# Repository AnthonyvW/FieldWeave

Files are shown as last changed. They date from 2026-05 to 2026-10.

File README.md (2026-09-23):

# FieldWeave - Low Cost Gigapixel Imaging Machine








FieldWeave is an open-source, gigapixel imaging system built on a modified off-the-shelf 3D printer. It automates sample capture, focus stacking, and DPI calibration, producing high resolution images across a wide range of fields. See it in action on the [FieldWeave website](https://www.fieldweave.com), which includes an interactive gallery for browsing full-resolution scans.

**If FieldWeave is useful to you, please consider giving it a star and supporting its development. See [Support FieldWeave](#support-fieldweave) below.**

## Features

* **Automated Scanning**: Utilizes 3D printer mechanics for precise, repeatable sample movement.
* **High-Resolution Imaging**: Captures gigapixel images across dendrochronology, geology, life sciences, museum, manufacturing, and forensic use cases.
* **Focus Stacking**: Built-in stacking via FocusWeave.
* **Automated DPI Calibration**: Calibrates scan resolution automatically against a compatible micrometer slide.
* **Modular Design**: Easily adaptable to different sample types, lenses, and imaging requirements.

## Examples

### [Browse the full gallery at fieldweave.com/gallery](https://www.fieldweave.com/gallery)

<table>
  <tr>
    <td width="33%">
      <a href="https://www.fieldweave.com/gallery/image/cross-section-1">
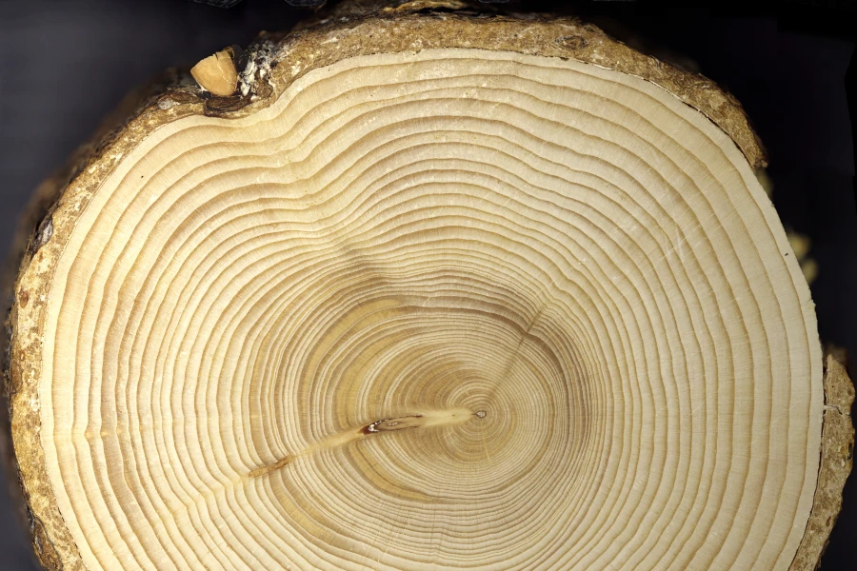
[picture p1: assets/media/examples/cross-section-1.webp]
Cross section of a black spruce tree core, click to view full resolution on the FieldWeave gallery
        
      </a>
    </td>
    <td width="33%">
      <a href="https://www.fieldweave.com/gallery/image/western-hemlock-core">
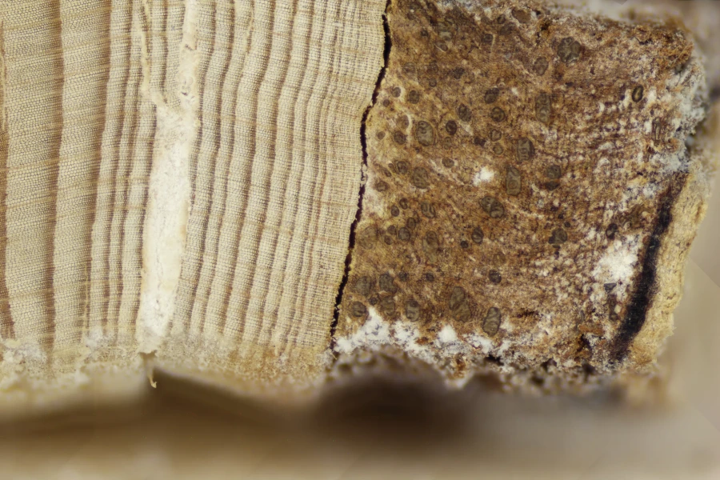
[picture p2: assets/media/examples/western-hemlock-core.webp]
Western hemlock tree core, click to view full resolution on the FieldWeave gallery
        
      </a>
    </td>
    <td width="33%">
      <a href="https://www.fieldweave.com/gallery/image/basswood-stem-cs">
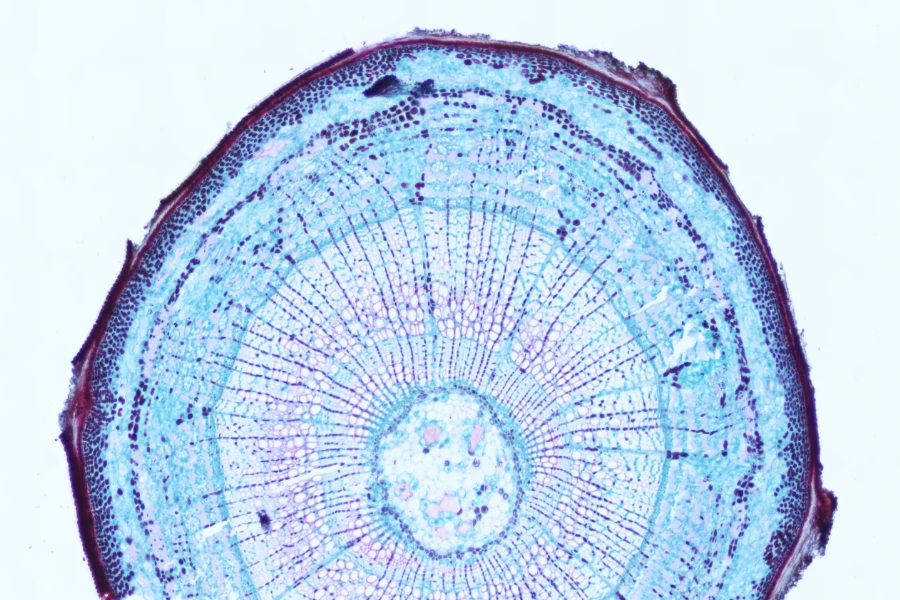
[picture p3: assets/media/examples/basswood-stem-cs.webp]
Cross section of a basswood stem, click to view full resolution on the FieldWeave gallery
        
      </a>
    </td>
  </tr>
	<tr>
    <th>Black spruce tree core cross section</th>
    <th>Western hemlock tree core</th>
    <th>Basswood stem cross section</th>
	</tr>
  <tr>
    <td width="33%">
      <a href="https://www.fieldweave.com/gallery/image/rusty-7-16-drill-bit">
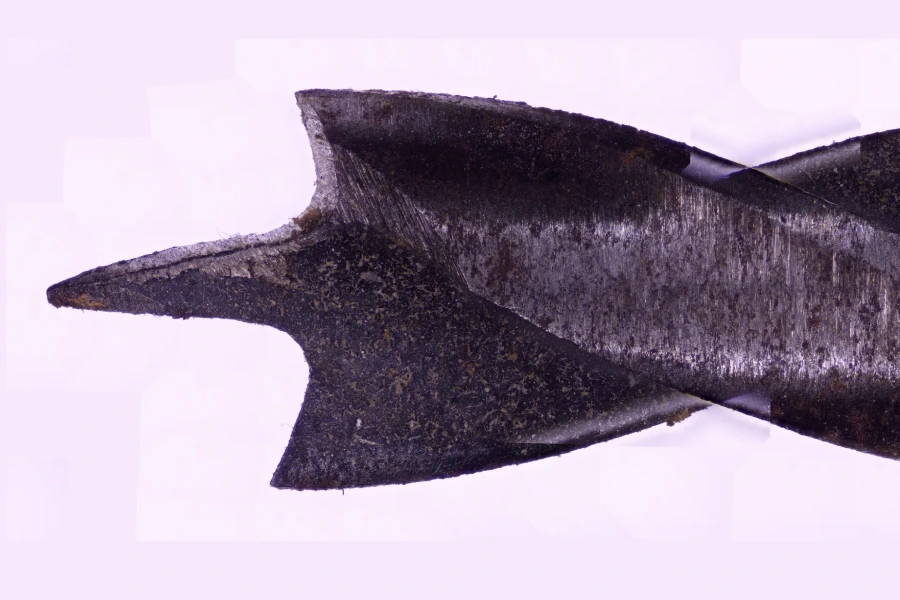
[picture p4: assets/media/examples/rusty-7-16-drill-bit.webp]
A rusty 7/16 drill bit, click to view full resolution on the FieldWeave gallery
        
      </a>
    </td>
    <td width="33%">
      <a href="https://www.fieldweave.com/gallery/image/us-dime-back">
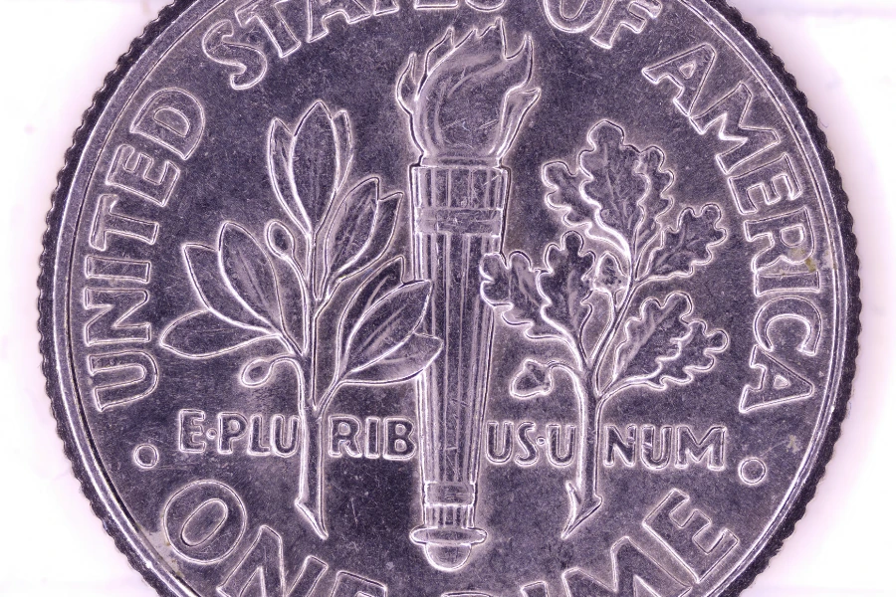
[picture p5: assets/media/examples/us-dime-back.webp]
Back of a US dime, click to view full resolution on the FieldWeave gallery
        
      </a>
    </td>
    <td width="33%">
      <a href="https://www.fieldweave.com/gallery/image/9mm-1">
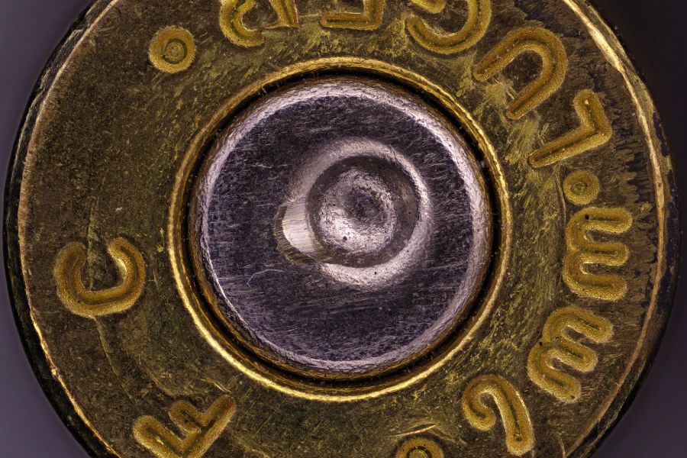
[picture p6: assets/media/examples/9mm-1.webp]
Spent 9mm bullet casing, click to view full resolution on the FieldWeave gallery
        
      </a>
    </td>
  </tr>
	<tr>
    <th>A rusty 7/16 drill bit</th>
    <th>Back of a US dime</th>
    <th>Spent 9mm bullet casing</th>
	</tr>
</table>

## Support FieldWeave

FieldWeave is free and GPL-licensed, and stays that way through community support. If it's useful to your lab, workflow, or project, consider chipping in. Funding goes directly toward hardware, testing, and development time.

* **GitHub Sponsors**: [github.com/sponsors/AnthonyvW](https://github.com/sponsors/AnthonyvW)
* **Ko-fi**: [ko-fi.com/procerand](https://ko-fi.com/procerand)

Have a specific feature your lab needs? [Commission a feature](https://www.fieldweave.com/contact) it gets built for you and becomes available to everyone.

## Getting Started

### Prerequisites

* **Hardware**: A [compatible 3D printer](#3d-printer-compatibility) modified for imaging purposes, a light, and a [compatible camera](#confirmed-compatible-cameras). The 3D printer may also require an additional cable to connect your PC to the printer. Note that this modification will likely void the warranty if you disconnect any cables, so test the 3D printer to ensure the motion system works before doing this.
  * For the light I recommend using the [Amscope 144 led ring light](https://www.amazon.com/dp/B00JZJO7YC). If you use this, make sure to 3D print the light pads to prevent scratching the lens.
  * If using an Amscope camera, I highly recommend using this ([100x Microscope Lens for Raspberry Pi](https://www.amazon.com/100X-Microscope-Lens-Magnification-Compatible/dp/B0C1CC79TX)) industrial lens as it provides minimal distortion around the edges.
    * If going for a higher end camera such as an Amscope MU2003, we recommend the Laowa 100mm f/2.8 2x Ultra Macro APO with an EF to C adapter. However, this will require a custom mount and a better motion system than what comes on a stock Ender 3 3D printer in order to withstand the increased weight.
  * Not required, but is recommended is a thumbscrew for holding the camera in place. I use thumbscrews from [this 16 piece set](https://www.amazon.com/dp/B0DQPM68KJ) from Amazon.
  * For the automated DPI calibration to work, a compatible micrometer calibration slide is required. It is confirmed to work with the [Amscope MR400 Stage Micrometer Calibration Slide with 4-Scales](https://amscope.com/products/mr400). I am interested in adding support for additional scales.
  * If you do not have access to a 3D printer capable of printing in at least 2 colors and wish to image tree core samples, then a roll of red electrical tape to denote the center of slots.
* **High Magnification Imaging Hardware**
  * Note: This is a more expensive version that achieves far greater magnification than most other setups, however it requires additional modifications. Instead of using the 100x lens listed above, use the following parts instead for the optics.
  * To successfully do this version with 10x objective it will require upgrading the leadscrews to [350mm Tr8X2 2mm lead](https://www.amazon.com/dp/B095M8SQQV?th=1) with the appropriate [anti backlash nuts](https://www.amazon.com/dp/B085GGMCVG?th=1)
  * For the tube lense I recommend using the [Raynox DCR 250 Lens](https://www.amazon.com/Raynox-DCR-250-Super-Macro-Snap/dp/B000A1SZ2Y/) as there are 3D models present that use that.
  * [M49 to RMS Adapter](https://www.amazon.com/dp/B0FHN8FQ7T) for connecting the microscope objective to the tube lens
  * [C Mount to M42 Adapter](https://www.amazon.com/dp/B0812QPHWN) for connecting the camera to the high magnification setup.
  * For the high magnification setup, 1/4" thumbscrews are required to hold the camera in place. I use thumbscrews from [this 16 piece set](https://www.amazon.com/dp/B0DQPM68KJ) from Amazon.
  * For the microscope objective I recommend either the [Amscope 4x Metallurgic objective](https://amscope.com/products/pl4x-inf-v300) or the [Amscope 10x metallurgic objective](https://amscope.com/products/pl10x-inf-v300) both objectives are infinity plan achromatic objectives. Using anything above 10x is not recommended due to the depth of field becoming shallower than what the machine is capable of moving.
  * Due to the depth of the holes on the 3D printed parts I recommend getting a set of longer than usual metric hex keys so you can screw everything in properly. I use [this set.](https://www.amazon.com/dp/B0000CBJDV) 
* **Software**: Python 3.x and Git
* **Operating System**: Linux, Windows 10, or Windows 11

## Printer Modification

Before using FieldWeave, your 3D printer must be modified to mount the camera system in place of the print head.

### Required Printed Parts

Before modifying your printer, you must 3D print the following components:

- **Camera Mount** - Ender 3 Camera Mount.3mf – Attaches to the existing print head carriage  
- **High Magnification Camera Mount Files** - high_magnification folder
  * These are only for if you are going with the high magnification version of FieldWeave.
  * MicroscopeObjectiveMount.3mf - Attaches to print head carriage
  * Light Baffles.3mf - Insert to objective mount after screwing the mount in.
  * Amscope Mount.3mf - Attaches to the print head carriage to hold camera in place
  * RaynoxRingLightBuffer.3mf - Use if using the amscope ring light with it. You will need 3 of these. These help hold the ring light still.
- **Z-Axis Spacer** - ZAxisSpacer.3mf – Raises the Z-axis endstop to accommodate the new camera height  
    - If you are proficient with working with electronics, I suggest replacing the Z axis end stop wires with longer ones instead and mounting the Z axis limit switch higher.

> files for these parts will be provided in the `hardware/` folder of this repository.

### Optional Printed Parts
- **Calibration Slide Tray** - If using a micrometer calibration slide, this tray holds it stationary on the bed of the machine while providing a solid colored background.
- **Sample Clips** – Secure tree core samples to the print bed without manual alignment
    - SampleHolderEnd.3mf
    - SampleHolderFooter.3mf - If printing the multicolor version ensure that all the tick marks are printed in a red filament.
    - SampleHolderMiddle.3mf - You will need 3 of these. I suggest printing one of these off and ensuring that it properly fits before printing off the rest of the parts.
---

### Modification Instructions

> ! IMPORTANT ! Ensure that you have all 3D printed parts before modifying your 3D printer.

1. **Unplug 3D Printer**  
   Ensure the 3D printer is disconnected from power before working on it.

2. **Remove the Print Head**  
   Unscrew and detach the printer's hotend from the X-axis print carriage.

3. **Disconnect Wiring**  
   Carefully disconnect the hotend and heatbed wiring from the printer's control board. This prevents accidental heating or movement of the removed components.

4. **Install Camera Mount**  
   Use the print head screws to attach the printed camera mount to the same location on the print carriage where the print head was originally mounted.

5. **Insert Z-Axis Spacer**  
   Add the printed Z-axis spacer on the Z endstop, so the camera does not crash while homing.

6. **Insert sample clips**
   If you choose to use sample clips then this is the stage where you would want to slide them onto the print bed. If you printed the footer in single color you will also want to mark the center of the slots (above the slot not in the slot) with a red mark. I recommend using red electrical tape as it doesn't fade.

7. **Install Camera and Lens**  
   - Insert your digital microscope or Amscope camera into the printed mount.  
   - Screw on the imaging lens securely.  
   
8. **Install Light**  
   Install the light you will be using with FieldWeave. 
   > If using the Amscope ring light, place the light pads onto the metal tips of the screws that hold the light in place before putting the light on the lens.

9. **Plug Everything in**  
   - Plug the 3D printer back into the wall
   - Plug the 3D printer into your computer via USB for motion control.  
   - Plug in the camera using its USB interface for image capture.
   - Plug in the Light

10. **Done**

### Installation

Prerequisites\. Ensure you have the latest version of python installed, and you have git installed.

> Python : https://www.python.org/downloads/  
> Git : https://git-scm.com/downloads

1\. Clone the repository:

   ```bash
   git clone https://github.com/AnthonyvW/FieldWeave.git
   cd FieldWeave
   ```

2\. Install the required Python packages:

  ```bash
  pip install -r requirements.txt
  ```

3\.1\. Download the Amscope SDK for your camera at https://amscope.com/pages/software-downloads if you are on mac or linux, download the windows version as it includes the files for those operating systems there.

3\.2\. Move the downloaded zipped folder into 3rd_party_imports

4\. Run the install scripts:

  Windows
  ```bash
  windows_install.bat
  ```
  Linux
  ```bash
  ./ubuntu_install.sh
  ```
5\. Start FieldWeave

  Windows
  ```bash
  windows_start.bat
  ```
  Linux
  ```bash
  ./ubuntu_start.sh
  ```

---
## Confirmed Compatible Cameras
FieldWeave supports USB cameras through a modular driver architecture.

| Camera Model | Notes |
|---|---|
| Amscope MU500 | Fully tested and supported  |
| Amscope MU1000 | Fully tested, the automatic DPI calibration does not work at this camera's max resolution |
| Amscope MU1000 HS | Fully tested, the automatic DPI calibration does not work at this camera's max resolution |
| Amscope MU2003 | Fully tested, the automatic DPI calibration does not work. In addition, it needs a custom mount and higher quality lenses compared to the cameras above. I recommend the Laowa 100mm f/2.8 2x Ultra Macro APO lens with an EF to C adapter. |
| Generic USB Camera | This was tested with 2 different USB cameras and is supported  |
| Other Amscope Cameras | They should work, but are not tested. Camera mount might need to be modfied for them to fit. |

⚠️ Amscope's SDK on their website is currently out of date as of 8/15/2026. If you contact Amscope support an up to date version can be provided. The SDK version I use is Version: 59.30149.20251130

### Adding Support for New Cameras

Users are encouraged to contribute new camera interfaces by implementing the FieldWeave camera interface and submitting them as pull requests.

If your camera is not currently supported or you would like to contribute an interfaces, please open an issue or submit a pull request.

Due to the complexity of hardware integration, especially with cameras requiring proprietary APIs or SDKs full support often requires physical access to the device for development and testing. If you would like me to implement support for your camera, please be prepared to ship the device or provide access to equivalent hardware.

Alternatively, contributions of driver implementations with thorough documentation and test instructions are highly appreciated.

## 3D Printer Compatibility

FieldWeave is designed to run on 3D printers using **Marlin firmware**, which supports standard G-code over USB serial. Compatibility with other firmware types varies and may require additional configuration or is not currently supported.

> Not sure if your 3D printer will work? Plug your printer into your computer via USB, and then start FieldWeave. If the printer homes then it is compatible with FieldWeave.

## Confirmed Compatible Printers

| Printer Model | Firmware | Build Volume (mm) | Notes |
|---|---|---|---|
| Ender 3 v1 | Marlin | 220 × 220 × 250 | Fully tested and supported. It is highly recommended that you use the official linear rail upgrade kit provided by Creality for the increased camera stability. |
| Creality CR-10S Pro v2  | Marlin | 300 × 300 × 400 | Fully tested; camera mount file not available. |
| Anycubic Kobra Max v1 | Marlin | 400 × 400 × 450 | Fully tested; camera mount file not available. |
---

> Want to help verify compatibility with other printers, firmware, or cameras?  
> [Open an issue](https://github.com/AnthonyvW/FieldWeave/issues) with your setup details and test results!

## Confirmed Incompatible Printers

| Printer Model | Build Volume (mm) | Notes |
|---|---|---|
| Bambulab A1 | 220 × 220 × 250 | Properietary Firmware, cannot send gcode directly to it  |

---

## Contributing

Contributions are welcome! Please fork the repository and submit a pull request with your enhancements. For major changes, open an issue first to discuss your proposed modifications.

Not able to contribute code? Financial support is just as valuable; see [Support FieldWeave](#support-fieldweave) above ([GitHub Sponsors](https://github.com/sponsors/AnthonyvW) / [Ko-fi](https://ko-fi.com/procerand)).

## Troubleshooting

**Camera freezes when taking pictures**
- Sometimes the serial drivers conflict with the camera drivers, to fix this, plug in the camera and the 3D printer into two different sides of the computer. This forces them to be on different usb controllers which fixes any conflicts they might have.

**My Camera isn't found**
- Make sure that you have the camera drivers installed. If your camera was previously found, but is no longer found, try unplugging it and plugging it back in and ensuring the OS detects that it is plugged in as it might be a bad cable.

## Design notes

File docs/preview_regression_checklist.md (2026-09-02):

# Camera Preview Regression Checklist

Manual verification checklist for the camera preview / measurement refactor
(see the interaction-mode, input-tool-dispatch, and measurement-kind-registry
work tracked against this branch). Run through this after any change to
`UI/widgets/camera_preview.py`, `UI/widgets/preview_overlay/`, or the tabs
that drive preview interaction mode, before considering that change done.

## Navigate tab
- [ ] Click on the live feed moves the stage (once machine vision is
      calibrated and motion is ready).
- [ ] Click does nothing while uncalibrated, or while an automation routine
      is running.
- [ ] Plain mouse wheel scroll moves the Z axis; Ctrl+scroll zooms instead.
- [ ] `+`/`=`/`-` zoom in/out; arrow keys pan while zoomed, and fall through
      to normal focus navigation while not zoomed.

## Measurement tab
- [ ] Click-to-move is fully suppressed (live feed and loaded image alike).
- [ ] Plain scroll zooms (same as Ctrl+scroll); there is no Z-move path.
- [ ] Selecting a measurement kind in the sidebar, then clicking once,
      starts a draft; a dashed preview line/shape follows the cursor
      between clicks with no button held.
- [ ] Completing the required number of clicks finalizes the measurement
      and it renders with its tag/label.
- [ ] Placing a measurement while zoomed in resolves to the correct
      underlying frame position (not the zoomed/panned widget position).
- [ ] Click-and-drag while a kind is selected pans the zoomed view instead
      of placing a measurement (drag threshold ~4px).
- [ ] Clicking directly on an existing measurement's endpoint (not
      currently placing a new one) starts an endpoint drag; dragging moves
      just that point, respecting kind-specific constraints (e.g.
      Horizontal Line keeps its row fixed).
- [ ] Right-click while a multi-point placement is in progress cancels the
      draft (Arbitrary Line instead finalizes if >=2 points already placed).
- [ ] Hovering a measurement's tag shows/highlights it without a prior
      click; a delete glyph appears and removing it deletes the
      measurement.
- [ ] Pressing Delete/Backspace while hovering a tag deletes that
      measurement, with no click required first.
- [ ] Clicking a tag (not the delete glyph) opens the customize menu;
      editing there live-previews on the placed measurement; Apply commits,
      Cancel reverts.
- [ ] Switching unit (e.g. mm to px) updates all displayed labels.
- [ ] Manual DPI calibration: starting it, clicking a two-point line,
      entering a real-world length, submitting, and cancelling all behave
      as today.
- [ ] Switching to "loaded image" mode shows the static image, measurements
      persist per-image, and switching images with existing measurements
      prompts a discard confirmation.
- [ ] Leaving the tab (switching to Navigate/Calibration/Project) restores
      click-to-move and Z-scroll on return to Navigate; measurement overlay
      is hidden while another tab is showing the shared preview.

## Calibration wizards
- [ ] Camera Space Calibration: crosshair shows on the appropriate step,
      restores to its prior state when leaving the wizard, and the final
      "verify" step's click-to-move still works (default preview behavior,
      no wizard-specific code).
- [ ] DPI Calibration: crosshair on step 1, inspect-calibration overlay on
      steps 2/3, both off afterward; tick-length slider updates the overlay
      live; overlay state (crosshair/inspect-calibration) restores to
      whatever it was before entering the wizard when finishing or
      resetting.
- [ ] Slot Calibration: red-mark overlay shows only on its designated
      steps and restores to its prior state afterward.
- [ ] Re-entering a wizard after finishing it once (via the launch list)
      resets its step to 1 and re-applies step-1 overlay state.

## Cross-cutting
- [ ] Switching tabs while zoomed in a measurement/loaded-image context
      does not leave zoom/pan state corrupted when returning.
- [ ] No overlay state "leaks" between tabs (e.g. crosshair left on after
      leaving a calibration wizard when it wasn't on beforehand).

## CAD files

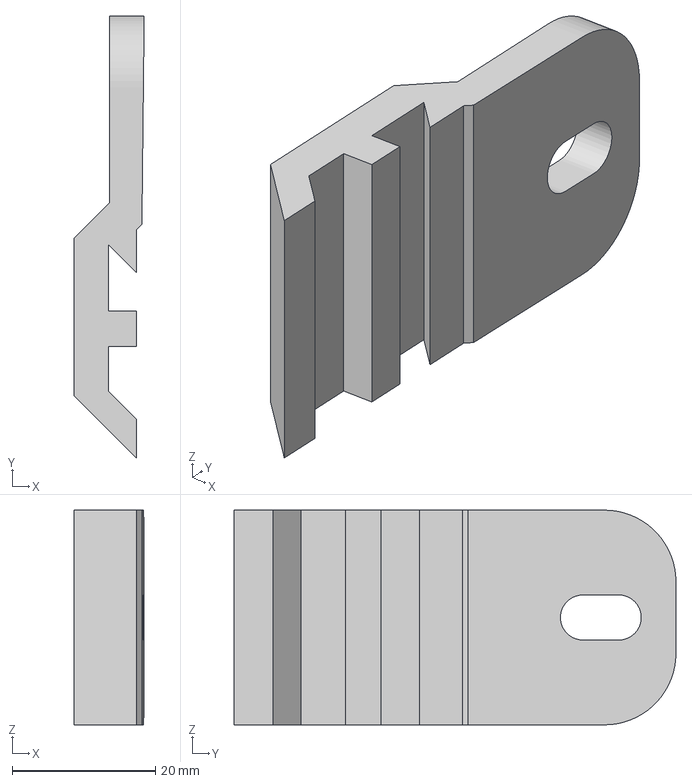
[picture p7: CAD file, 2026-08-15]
hardware/high_magnification/Amscope Mount.3mf
9.84 x 61.7 x 30.0 mm

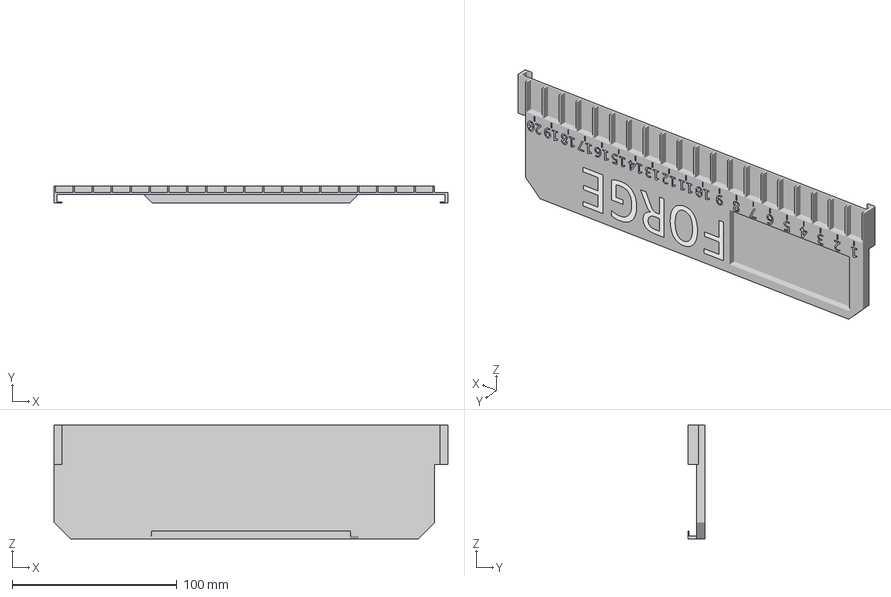
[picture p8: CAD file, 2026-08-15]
hardware/SampleHolderFooterMultiColor.3mf
239.0 x 10.3 x 69.0 mm
SampleHolderFooter

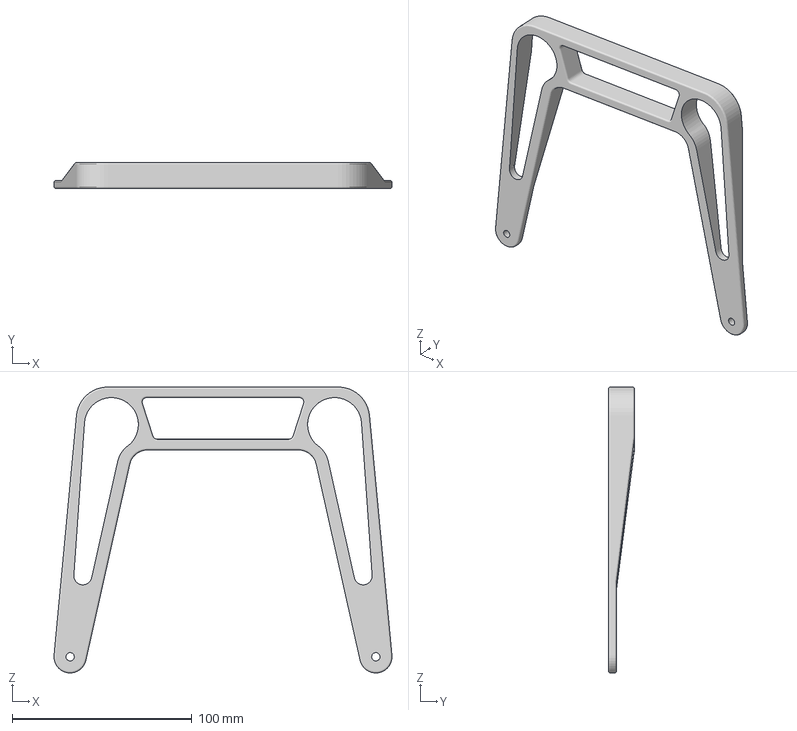
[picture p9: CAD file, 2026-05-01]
hardware/handle.3mf
187.9 x 14.5 x 159.0 mm

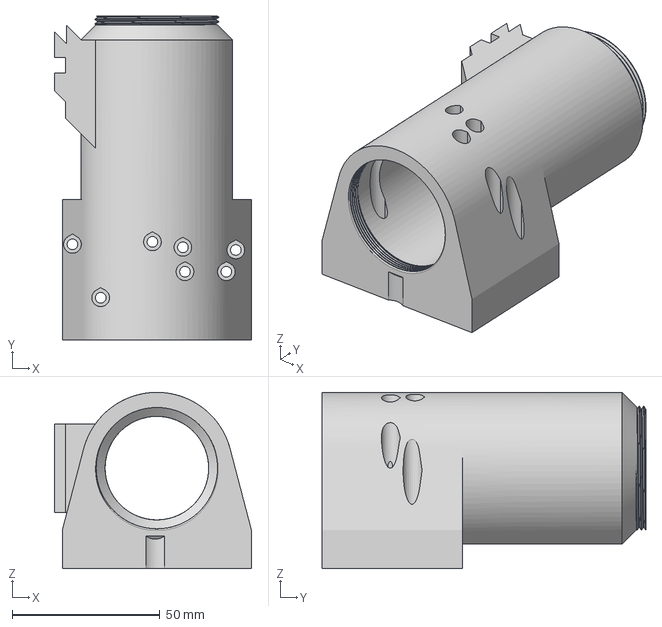
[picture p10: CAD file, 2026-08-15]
hardware/high_magnification/MicroscopeObjectiveMount.3mf
66.6 x 109.5 x 59.6 mm

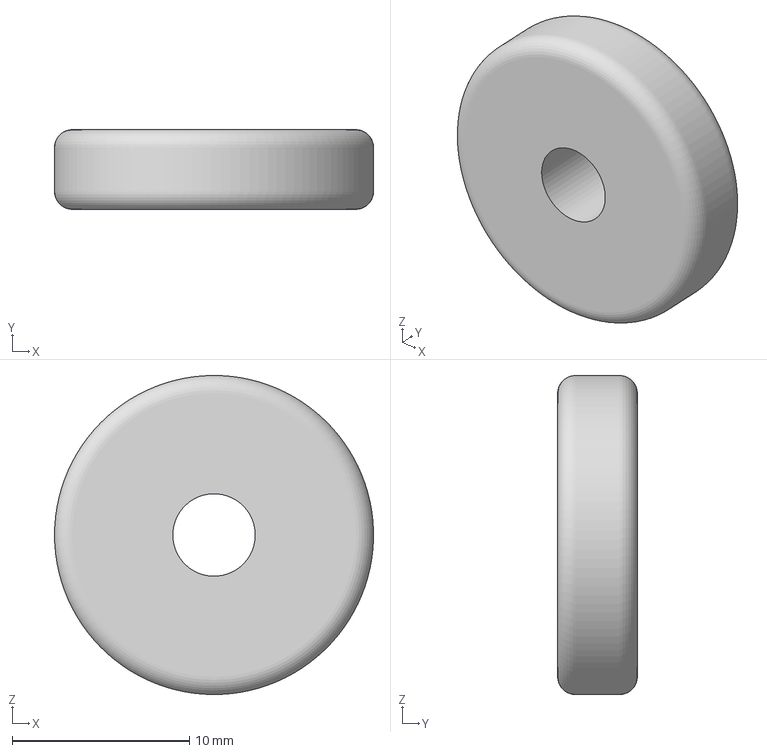
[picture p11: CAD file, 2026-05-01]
hardware/bedspacer.3mf
18.0 x 4.50 x 18.0 mm

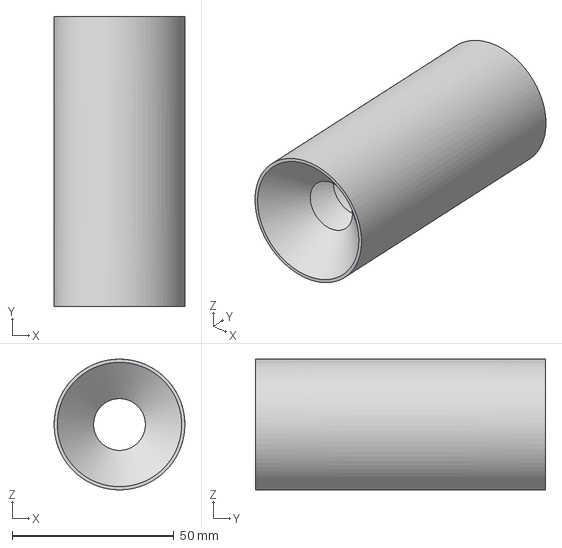
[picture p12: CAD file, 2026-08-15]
hardware/high_magnification/Light Baffles.3mf
40.4 x 89.6 x 40.4 mm

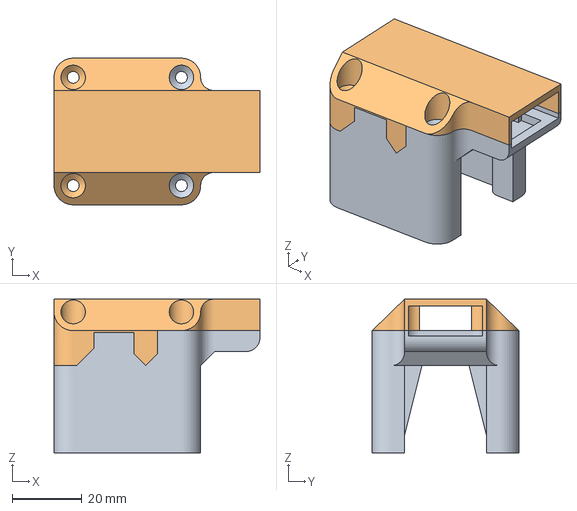
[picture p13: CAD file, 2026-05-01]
hardware/X Axis Motor Cover.3mf
59.0 x 42.0 x 44.0 mm

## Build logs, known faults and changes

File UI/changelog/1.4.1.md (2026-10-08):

# What's Changed
---
This update is focused around fixing bugs and allowing the user to control which version of FieldWeave they use.

As usual, if you come across any bugs while using FieldWeave, have feedback, or just want to request new features, please send them to <contact@FieldWeave.com> or open an issue on Github at <https://github.com/AnthonyvW/FieldWeave/issues/new>

# New Features & Improvements
---
- Added ability to switch to old versions of FieldWeave.
- Added ability to switch to beta versions of FieldWeave.

# Bugfixes
---
- Fixed the slot calibration page not using the appropriate axis.
- Taking multiple pictures in one second will no longer overwrite the old picture.

# Known bugs
---
- Automatic DPI calibration fails if slide isn't perfectly straight.
- Automatic DPI calibration tends to fail when using high resolution imagery.

# Support FieldWeave
---
FieldWeave is free and open source, and stays that way through community support. If it's useful to your lab, workflow, or project, consider chipping in. Funding goes directly toward hardware, testing, and development time.

* **GitHub Sponsors**: [github.com/sponsors/AnthonyvW](https://github.com/sponsors/AnthonyvW)
* **Ko-fi**: [ko-fi.com/procerand](https://ko-fi.com/procerand)

Have a specific feature your lab needs or just want to give feedback? [Contact us through the contact form](https://www.fieldweave.com/contact) or email us at <contact@fieldweave.com>

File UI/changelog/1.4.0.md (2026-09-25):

# What's Changed
---
This update comes with a lot of quality of life improvements for both area scans and tree core scans. For tree core scans the most notable improvement is the new option for automated image stitching along with automatically taking a single picture of the calibration slide before every tree core! It's currently a known issue that the automatic DPI calibration tends to fail, as such the singular image option was added as a backup. No more having to manually take an image of the calibration slide before hand! just set it once and then leave it there with the option checked and it'll do it every time going forward. 

As usual, if you come across any bugs while using FieldWeave, have feedback, or just want to request new features, please send them to <contact@FieldWeave.com> or open an issue on Github at <https://github.com/AnthonyvW/FieldWeave/issues/new>

# New Features & Improvements
---
- Added image stitching for tree core automation.
- Added option to take a single photo of a calibration slide for tree core imaging routines.
- Added option to image calibration slide before imaging all tree core samples.
- The load image feature can now convert tiffs into tiffs with pyramids vastly decreasing future loading times.
- The OS will no longer go to sleep when doing an imaging routine for both Windows and Debian based Linux distros.
- If the motion controller has issues, automations will now pause instead of continuing in a faulted state.
- Improved image loading speeds when using the load image feature in the measurement tab.
- The load image feature can now convert tiffs into tiffs with pyramids vastly decreasing future loading times.
- Multiple focus stacking routines can be ran concurrently for area scans, this can be found in the focus stacking advanced settings under "Concurrent Stacks".
- Area scans now state the time and date of when they'll be done.
- Time estimates are now more accurate for taking photos.
    - Per camera, per resolution time estimates are now saved and used in the automation time estimates.
    - Focus stacking now keeps track of time and provides a time estimate.
    - Automation now displays total estimated time including focus stacking.
    - Actual travel time is now taken into account. This will go into effect after an area scan is done.
- Camera calibration now gives feedback on whether or not a calibration is bad.
- Last used COM port is now saved.
- Last used camera is now saved.
    - These two changes combined allow two separate copies of FieldWeave to run on the same machine if it has sufficient resources.
- Can now disable individual axis
- Can now disable homing per axis
- Improved performance of logs tab.
- Logs tab auto scroll only applies when you're at the bottom of the logs now.

# Bugfixes
---
- Load Image in the measurements tab no longer consumes multiple gigabytes of ram when opening images with pyramids.
- Fixed race condition that occasionally appears when doing focus stacks in the tree core imaging routine causing the focus stack to fail.
- Fixed click to move failing on high resolution images.
- Fixed issue where switching away from a USB camera before it was ready caused an error.
- Fixed issue where navigation widget didn't grey out while homing.

# Known bugs
---
- Automatic DPI calibration fails if slide isn't perfectly straight.
- Automatic DPI calibration tends to fail when using high resolution imagery.

# Support FieldWeave
---
FieldWeave is free and open source, and stays that way through community support. If it's useful to your lab, workflow, or project, consider chipping in. Funding goes directly toward hardware, testing, and development time.

* **GitHub Sponsors**: [github.com/sponsors/AnthonyvW](https://github.com/sponsors/AnthonyvW)
* **Ko-fi**: [ko-fi.com/procerand](https://ko-fi.com/procerand)

Have a specific feature your lab needs or just want to give feedback? [Contact us through the contact form](https://www.fieldweave.com/contact) or email us at <contact@fieldweave.com>

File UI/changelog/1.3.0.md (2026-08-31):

# What's Changed
---
FieldWeave now has a changelog! It will display after every update, if you miss it and want to view it again, you can do so in the about page in the settings.

# New Features & Improvements
---
- Added patch number to versioning scheme
- Added patch notes pop up
- Added button to view patch notes in the about page in settings
- Can now use the arrow keys to navigate when zoomed in
- Focus stacked images now preserve image metadata
- Added Measurement Tab
    - Added image viewer capable of handling terapixel images
    - Added manual DPI calibration
    - Added 7 measurement types
- Added method for getting current camera still resolution

# Bugfixes
---
- Version field in config files now successfully migrates and is saved
- Fixed the post processing manager creating a redundant config
- While developing it will no longer warn about failing to update.
- Toasts no longer throw errors if you close the program while one is active.
- Fixed Amscope cameras not saving all camera metadata.
- Fixed Tiff writer not saving metadata.
- Camera metadata now saves to the proper metadata fields.

# Support FieldWeave
---
FieldWeave is free and open source, and stays that way through community support. If it's useful to your lab, workflow, or project, consider chipping in. Funding goes directly toward hardware, testing, and development time.

* **GitHub Sponsors**: [github.com/sponsors/AnthonyvW](https://github.com/sponsors/AnthonyvW)
* **Ko-fi**: [ko-fi.com/procerand](https://ko-fi.com/procerand)

Have a specific feature your lab needs or just want to give feedback? [Contact us through the contact form](https://www.fieldweave.com/contact) or email us at <contact@fieldweave.com>

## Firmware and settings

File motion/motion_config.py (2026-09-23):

from __future__ import annotations

from dataclasses import dataclass, field, asdict, fields
from pathlib import Path
from typing import Any

from common.generic_config import ConfigManager

AXES: tuple[str, ...] = ("x", "y", "z")

# Default jog-step presets in nanometres (0.04 mm, 0.4 mm, 2.0 mm, 10.0 mm).
_DEFAULT_STEP_PRESETS_NM: list[int] = [40_000, 400_000, 2_000_000, 10_000_000]


@dataclass
class CameraCalibrationPosition:
    """Saved stage position used as the starting point for camera calibration.

    Coordinates are stored in nanometres.  ``last_calibrated_iso`` holds the
    ISO-8601 timestamp of the most recent successful calibration, or an empty
    string if no calibration has been completed yet.
    """

    x_nm: int = 0
    y_nm: int = 0
    z_nm: int = 0
    last_calibrated_iso: str = ""
    is_set: bool = False

    @property
    def has_been_calibrated(self) -> bool:
        """True if a successful calibration has been recorded."""
        return bool(self.last_calibrated_iso)


@dataclass
class TreeCoreSlot:
    """A single slot in a tree core slide.

    ``position_nm`` is the coordinate along the automation axis for this slot.
    ``offset_nm`` is an additional fine-tune offset applied on top of the slot
    position, also along the automation axis.
    """

    position_nm: int = 0
    offset_nm: int = 0


@dataclass
class TreeCoreAutomationSettings:
    """Settings for automated tree core slot imaging.

    The stage steps along a fixed axis (currently Y) to image each slot in
    sequence.  A mark is imaged at a known X/Y position before the run begins.

    All positions and offsets are in nanometres.
    """

    # Axis driven during automation — hard-coded to Y for now.
    axis: str = "y"

    # Position of the reference mark imaged before the run.
    mark_reference_nm: int = 0
    mark_z_nm: int = 0

    # Z height to move to at the start of the run.
    starting_height_nm: int = 0

    # Offset applied along the automation axis before the first slot.
    starting_offset_nm: int = 0

    # Distance between consecutive slots along the automation axis.
    slot_separation_nm: int = 11_200_000

    # ISO-8601 timestamp of the most recent successful calibration, or an empty
    # string if no calibration has been completed yet.
    last_calibrated_iso: str = ""

    image_name_template: str = "Y{y}_X{x}_Z{z}"

    # Distance the stage moves between frames.  0 derives it from
    # image_overlap and the camera calibration.
    step_distance_nm: int = 0

    # Fractional overlap between neighbouring frames.  Kept in step with
    # step_distance_nm through the camera calibration's field of view, so it
    # is only meaningful once the camera has been calibrated.
    image_overlap: float = 0.4

    # Stitch each core's frames into one image once they are all captured
    # (and focus stacked, in focus stack mode).
    stitch_enabled: bool = True

    # The stitching overlap normally follows from the step distance and the
    # camera calibration (or is measured from the images).  When True,
    # stitch_overlap is used instead.
    stitch_overlap_override: bool = False
    stitch_overlap: float = 0.4

    # Imaging mode: "optimal_focus" uses autofocus at each position;
    # "focus_stack" captures a Z-stack and stacks the result.
    focus_mode: str = "optimal_focus"

    # When True the calibration slide is imaged during the run.
    calibration_scale_enabled: bool = False

    # Calibration slide imaging: "single" captures one photo (no DPI
    # measurement); "stitched" walks the scale bar and measures DPI.
    calibration_scale_mode: str = "stitched"

    # When True the calibration slide is imaged before every slot instead of
    # once after all slots are complete.
    calibration_scale_per_slot: bool = False

    # Focus stack parameters (used when focus_mode == "focus_stack").
    z_step_nm: int = 200_000
    z_near_plane_nm: int = 0
    z_far_plane_nm: int = 0

    # Focus stack — advanced
    keep_size: bool = True
    no_align: bool = False
    crop: bool = False
    sharpness: float = 4.0
    cull_enabled: bool = True
    cull_threshold: float = 0.6
    slab_enabled: bool = False
    slab_size: int = 20
    slab_overlap: int = 5
    workers: int = 3

    # Ordered list of slot definitions (defaults to 20 empty slots).
    slots: list[TreeCoreSlot] = field(default_factory=lambda: [TreeCoreSlot() for _ in range(20)])

    @property
    def num_slots(self) -> int:
        return len(self.slots)

    @property
    def has_been_calibrated(self) -> bool:
        """True if a successful calibration has been recorded."""
        return bool(self.last_calibrated_iso)


@dataclass
class ZStackScanSettings:
    """Persisted defaults for the Z-stack scan and focus stack routine.

    Scan parameters
    ---------------
    step_nm:
        Distance between capture positions in nanometres.
    approach_distance_nm:
        Overshoot distance before the scan begins to eliminate backlash.
        0 disables the approach move.

    Focus stack parameters
    ----------------------
    All fields correspond directly to the controls in FocusStackWidget and
    are forwarded to FocusStackRoutineConfig when a scan is started.
    """

    # Scan
    step_nm: int = 200_000
    approach_distance_nm: int = 400_000
    image_name_template: str = "{z}"
    stacked_name_template: str = "stacked"

    # Focus stack — top-level toggles
    run_focus_stack: bool = True
    keep_size: bool = True

    # Focus stack — advanced
    no_align: bool = False
    crop: bool = False
    sharpness: float = 4.0
    cull_enabled: bool = False
    cull_threshold: float = 0.6
    slab_enabled: bool = False
    slab_size: int = 20
    slab_overlap: int = 5
    workers: int = 3
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

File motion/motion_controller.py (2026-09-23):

from __future__ import annotations

import errno
import re
import sys
import threading
import time
from dataclasses import dataclass, field
from queue import Queue
from typing import Callable

import serial
import serial.tools.list_ports

from common.logger import info, error, warning, debug

from motion.models import Position
from motion.motion_config import AXES, MotionSystemSettings, MotionSystemSettingsManager

_NM_PER_MM = 1_000_000


def _is_move(gc: str) -> bool:
    """Return True if *gc* is a G-code command that produces physical motion."""
    return gc.upper().split()[0] in ("G0", "G1", "G28")


def _g28_axes(gc: str) -> tuple[str, ...]:
    """Axes homed by a G28 command; a bare G28 homes every axis."""
    named = tuple(a for a in AXES if a.upper() in gc.upper().split()[1:])
    return named or AXES


def _probe_port(
    port_device: str,
    baud: int,
    indicators: list[str],
    request: bytes = b"M115\r\n",
    read_window_s: float = 10,
    min_lines: int = 3,
    stop_event: threading.Event | None = None,
) -> tuple[serial.Serial | None, list[str]]:
    """
    Try to identify a Marlin-like printer on a single serial port.

    Returns (serial_connection, response_lines) on success, or
    (None, response_lines) on failure.  On success the connection is left
    open for the caller.  Probing is abandoned early if *stop_event* is set.
    """
    def stopped() -> bool:
        return stop_event is not None and stop_event.is_set()

    responses: list[str] = []
    ser: serial.Serial | None = None
    success = False
    try:
        # Exclusive so another process (or a stale controller) holding the
        # port on Linux makes the open fail instead of silently sharing it.
        ser = serial.Serial(port_device, baudrate=baud, timeout=1, write_timeout=1, exclusive=True)

        # Some controllers reset on open due to DTR; allow them to chatter.
        start = time.time()
        quiet_since = start
        while time.time() - start < 2.0 and not stopped():
            while ser.in_waiting:
                line = ser.readline().decode("utf-8", errors="ignore").strip()
                if line:
                    responses.append(line)
                    quiet_since = time.time()
            if time.time() - quiet_since > 0.25:
                break
            time.sleep(0.05)

        ser.reset_input_buffer()
        ser.write(request)

        start = time.time()
        while time.time() - start < read_window_s and not stopped():
            if ser.in_waiting:
                line = ser.readline().decode("utf-8", errors="ignore").strip()
                if line:
                    responses.append(line)
                    if any(ind in line for ind in indicators):
                        success = True
                        break
                    if len(responses) >= min_lines and time.time() - start > 3:
                        success = True
                        break
            else:
                time.sleep(0.05)

        return (ser, responses) if success else (None, responses)

    except serial.SerialException as exc:
        hint = ""
        if exc.errno == errno.EACCES and sys.platform.startswith("linux"):
            hint = " (add your user to the 'dialout' group and log in again)"
        warning(f"Could not open {port_device}{hint}: {exc}")
        return None, responses

    except Exception:
        return None, responses

    finally:
        if ser is not None and ser.is_open and not success:
            try:
                ser.close()
            except Exception:
                pass


class MotionState:
    """Current lifecycle state of the motion controller."""
    CONNECTING = "connecting"    # Worker thread is still starting up / probing serial
    HOMING     = "homing"        # Connected to printer, running a homing sequence
    READY      = "ready"         # Connected, homed, and accepting commands
    FAULTED    = "faulted"       # Runtime fault (bad G-code response, timeout, etc.)
    FAILED     = "failed"        # Could not connect at all during initialisation


class MotionFault(Exception):
    """Raised when the printer reports an unrecoverable error."""


class MotionTimeout(Exception):
    """Raised when the printer does not respond within the expected window."""


@dataclass
class _Command:
    gcode: str
    message: str | None = None
    log: bool = False
    done: threading.Event = field(default_factory=threading.Event)


class MotionController:
    """
    Minimal motion controller for a Marlin-based 3D printer / motion system.

    Responsibilities
    ----------------
    - Discover the printer port via _probe_port.
    - Home on startup.
    - Accept G-code move commands via a thread-safe queue.
    - Track the current position in nanometres.
    - Provide move_axis and move_to_position helpers.
    - Expose a simple message-listener hook for UI feedback.
    """

    def __init__(self, config: MotionSystemSettings | None = None) -> None:
        self._config_manager = MotionSystemSettingsManager()
        self.config: MotionSystemSettings = config if config is not None else self._config_manager.load()

        self.position = Position(0, 0, 0)
        self.faulted = False
        # Replaced rather than mutated so the UI can read it from another thread.
        self.homed_axes: frozenset[str] = frozenset()

        self._ready = threading.Event()
        self._homing = False
        self._home_done: threading.Event | None = None
        self._init_error: Exception | None = None

        self._stop_event = threading.Event()

        self._command_queue: Queue[_Command] = Queue()
        self._message_listeners: list[Callable[[str, bool], None]] = []

        self._thread = threading.Thread(target=self._worker, daemon=True)
        self._thread.start()

    # ------------------------------------------------------------------
    # State
    # ------------------------------------------------------------------

    def get_state(self) -> str:
        """Return the current :class:`MotionState` of the controller."""
        if self._init_error is not None:
            return MotionState.FAILED
        if self.faulted:
            return MotionState.FAULTED
        if not self._ready.is_set():
            return MotionState.HOMING if self._homing else MotionState.CONNECTING
        home_done = self._home_done
        if home_done is not None and not home_done.is_set():
            return MotionState.HOMING
        return MotionState.READY

    @property
    def connection_error(self) -> str | None:
        """Why connecting failed, or None if it has not failed (or was cancelled by shutdown)."""
        if self._init_error is None or self._stop_event.is_set():
            return None
        return str(self._init_error)

    def is_ready(self) -> bool:
        """Return True once the printer has been found and homed."""
        return self.get_state() == MotionState.READY
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

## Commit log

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2026-03-30 formatting, and fixed caught error
    [motion_config.py, motion_controller.py, motion_controller_manager.py]
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2026-04-14 Automation now waits and output path is now correct
    [motion_controller.py, motion_controller_manager.py]
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2026-04-23 Can no longer mess up automation by moving during it
    [motion_controller.py]
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2026-05-05 removed printer folder as it's no longer required
    [models.py]
2026-05-05 default saved config is no longer a thing
    [motion_config.py]
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2026-05-07 camera widget no longer asks if you want to save settings upon init
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2026-08-17 Removed zoom preview mode and added buttons and shortcuts for controlling zoom
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2026-09-02 Refactor camera preview interaction and measurement architecture
    Replaces the three ad-hoc mechanisms tabs used to tell the shared
    camera preview what mode to be in (Navigate's implicit defaults,
    Measurement's single fan-out boolean, each calibration wizard's
    hand-rolled overlay save/restore) with one stack-based
    PreviewModeSpec/PreviewModeController contract, so pushing a mode
    always restores exactly the prior state on pop regardless of what
    else changed in between.
    Decomposes OverlayLabel's ~220-line per-event if/elif dispatch chain
    (click-to-move, zoom-pan, measurement placement/drag, tag hover) into
    composable InputTool objects tried in registration order via a
    ToolDispatcher, so a new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
2026-09-03 Fix measurement-tab rendering bugs and redesign export/import UI
    Bug fixes:
    - Replace ChannelOverlay's slow float32 grayscale pipeline with
    cv2.transform, fixing the grayscale-toggle freeze (~9x faster on the
    hot path).
    - Give dashed line styles a SquareCap stroker so each dash gets an
    outline around its own ends, matching how circles already render.
    - Union all of an Arbitrary Line's segment paths before painting
    (_stroke_paths + _draw_polyline) instead of once per segment, so
    interior joints no longer show a doubled border.
    - Anchor a circle's tag at the same raw frame dims it was actually
    drawn against, keeping the length/diameter suffix on the DPI
    reference dims — fixes o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
2026-09-03 Fix Capture Control overflow, unify Take Photo with export, relocate measurement buttons
    - Fix the export-kind combo's size-adjust policy so its closed-state
    width no longer grows to fit its longest item's text, which was
    stretching the Capture Control group past the sidebar's width.
    - Remove the standalone "Export..." button; "Take Photo" now dispatches
    on the export-kind combo instead — a real camera sensor capture for
    the new "Full-res image (no measurements)" kind (Live mode only,
    unchanged), or a render-and-save of whatever is currently displayed
    for every other kind (works in Live or Loaded-Image mode), with no
    file-dialog prompt either way. Add a matching "Preview imag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
2026-09-03 Fix real Capture Control overflow, restore 4-column tiles, box export/import
    The previous round's overflow fix verified fine headless but never applied
    the app's real stylesheet, which adds meaningfully more per-widget padding
    than bare Qt defaults (QComboBox reserves 28px for its dropdown arrow,
    QPushButton adds its own padding+border) — re-measuring with the real
    stylesheet applied confirmed the sidebar was still genuinely overflowing.
    - Shorten the "Browse Output" button to "Open Folder" — the actual
    binding constraint on Capture Control's minimum width.
    - Move the export-kind combo to its own full-width row below "Take
    Photo" instead of sharing a row with a "Capture:" label; dro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
2026-09-03 Bigger tile icons, fix preview export ignoring zoom/pan
    - Bump ICON_SIZE (32->36) and POINT_RADIUS (5->6) so measurement-type
    tile icons read as more proportionate to their text, verified to
    still fit within the fixed tile size with real margin (not just
    barely).
    - Add ZoomPreviewOverlay.extract_current_view(), returning the current
    pan/zoom viewport's pixels at full source resolution.
    - CameraPreview._current_preview_frame_image() now crops to that
    viewport before scaling when zoomed, instead of always exporting the
    fully zoomed-out frame regardless of the live view's actual zoom
    state — this was why "Take Photo" with a preview export kind never
    reflected the current zoom.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
2026-09-03 Fix open-arrow tip/scaling, delete-X scope, and hover-reveal description
    - Open-arrow cap: the shaft is now shortened the same way the solid arrow's
    is, so its flat end no longer squares off the barb's sharp point
    - arrow_dims' floor sizes (the minimum arrowhead size for thin lines) are
    now divided by stroke_scale like every other fixed-on-screen-size value
    in this module, instead of being applied to the already-divided line
    width — previously the floor dominated at the default line width even
    unzoomed, and then grew unboundedly with the zoom multiplier since it
    wasn't itself zoom-compensated
    - The tag's delete (X) glyph is now confined to the header row — the strip
    no long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
2026-09-03 Fix open-arrow gap, add bracket cap, and Arrow/Bracket tiles
    - Fix the open-arrow shaft disconnecting from its barbs: the shaft was
    being shortened by the full arrow length (matching the solid arrow's
    reach), but the open barbs are only line-width wide even at their own
    base, nowhere near the shaft's width that far back — leaving a visible
    gap. It's now shortened by exactly the barbs' own miter overhang
    (shared via a new _arrow_open_miter_overhang helper), which is where
    the barb's own width first grows to match the shaft's.
    - Add a "bracket" line cap: a perpendicular tick sized off arrow_dims'
    half-width, flush at the endpoint (no shaft shortening needed, like
    "square").
    -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
2026-09-03 Add 3-point and 4-point angle measurement kinds
    - New "angle" MeasurementKind category: rather than a length, its tag
    shows the angle (degrees) between two line segments — segment_pairs
    supplies the (possibly partial, while still placing) segments to draw
    and hit-test, angle_value computes the angle in true pixel space
    (not fraction space, so it's correct regardless of the frame's own
    aspect ratio), angle_anchor gives the tag's anchor point.
    - "3 Point Angle": a vertex (the 2nd point) with two connected segments
    — same placement rhythm as "Arbitrary Line" but capped at 3 points.
    - "4 Point Angle": two independent, disconnected segments — drawn and
    hit-tested as two separa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
2026-09-04 Fix angle-tool joints and add leg-length/angle-indicator options
    - "3 Point Angle" now draws its two legs as one properly-joined polyline
    (via MeasurementKind.connected_segments), the same union "Arbitrary
    Line" uses, instead of two independently-stroked segments that
    doubled up the stroke/outline at the shared vertex. "4 Point Angle"'s
    genuinely disconnected segments are unaffected.
    - Add meta.show_leg_lengths (default off): appends each leg's own
    length to the tag, after the angle value.
    - Add meta.show_angle_indicator (default off): a dashed guide from each
    leg's nearer end to the angle's anchor (skipped for "3 Point Angle",
    whose legs already meet there) plus a small curved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
2026-09-04 Expand parallel/perpendicular tools and add Multipoint Line
    Replace the single Parallel/Perpendicular line kinds with families:
    - 3pt/4pt/8pt/arbitrary parallel, tagging the perpendicular gap between
    lines and drawing dashed connectors (or, for 8pt, dashed midlines)
    - 3pt/4pt/arbitrary perpendicular, drawing the derived perpendicular
    line dashed and tagging its length
    - Multipoint Line: an unbounded polyline like Arbitrary Line, distinct icon
    Generalize the line_pair category with connector_segments (dashed guides),
    pair_distance (gap/length labels), and cancel-to-finish for any unbounded
    kind via a min_points threshold.
    Claude-Se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
2026-09-04 Refine measurement icons, category tab behavior, and tag layering
    - All tile anchor points use the shared orange/blue idle/selected color
    (revert the forced-blue arrow tip; give the double arrow real points)
    - Update arbitrary-line, two-circle, and diameter-annulus icons
    - Two-circle center connector drawn solid; circles spaced, points offset
    - Category content left-aligned; picking a category selects its first (or
    last-used) tile
    - Remove the 3pt Square measurement
    - Draw all geometry before any tag, so a filled shape can't cover another
    measurement's tag
    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
2026-09-04 Rework parallel/perpendicular geometry, tags, and connectors
    - Parallel tools use dimension-line connectors: a perpendicular dashed
    line from the second line to the first, plus a collinear extension when
    the foot lands past the reference segment
    - 8pt parallel locks all four lines parallel to the reference, shows the
    first midline once two lines exist and the gap line when all are placed;
    icon shows four diagonal parallel lines with anchor points
    - Arbitrary parallel shows a distance tag for each gap between lines
    - 3pt perp draws both legs solid with a separate tag per line; 4pt perp
    draws the perpendicular line solid with a dashed connector to line 1;
    arbitrary perp draws solid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
2026-09-04 Indicator line, wheel guard, parallel snapping, and icon fixes
    - Unify the secondary dashed lines (parallel/perpendicular connectors and
    the angle indicator) into a customizable "indicator line": color,
    opacity, dash style, on/off, default on. Angles show it by default now.
    - Parallel/perpendicular lines stay solid while placing; only their
    indicator connectors dash. Arbitrary parallel draws a dashed connector
    at each gap tag.
    - 4pt/8pt parallel snap their derived control points onto the drawn,
    parallel-locked line ends after placement and each drag.
    - Block the scroll wheel from cycling combo/spin/slider values (forwarded
    to the surrounding scroll area instead).
    - _set_pen reset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
2026-09-04 Scrollable customize popup with delete, and dismissable extra tags
    - The customize popup caps its height and scrolls its fields, keeping the
    Apply/Cancel row and a new "Delete measurement" button (with a
    confirmation) always visible in a fixed footer.
    - Secondary distance tags are now hoverable; pressing Delete while
    hovering one dismisses just that tag (recorded in meta.hidden_extra)
    instead of deleting the whole measurement.
    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
2026-09-04 Arrowhead variants, placement preview, renames, and perp fixes
    - Solid arrowhead overlaps the shaft (no seam); add diamond and circle
    arrowhead cap variants with menu icons
    - Arrow caps show on the dashed placement preview
    - Shorten tile labels within each category (Arbitrary, 3 Point, ...);
    rename Arrow/Bracket category titles to "... Measurements"
    - 4pt perp snaps its control point onto the perpendicular line end
    - Arbitrary perp shows a length tag per perpendicular line
    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
2026-09-04 Draggable secondary tags, reset-style, windowed popup
    - Secondary (extra_measures) tags are now draggable (per-tag offset in
    meta.extra_offsets) and click to open the measurement's customize menu
    - Parallel gap tags anchor on their perpendicular connector so they sit
    by the indicator line
    - Add a "Reset Style" button that resets a measurement to the current
    default (keeping title/description) and restores hidden tags
    - The customize popup is now a real top-level window: draggable outside
    the preview frame, and its close button acts like Cancel
    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
2026-09-04 Polish customize popup: styling, layout, and annotation icons
    - Reset Style button now sits at the bottom of the scrollable field
    list instead of the fixed footer.
    - Customize popup restyled to match the app's panel look (window
    background, QGroupBox-style border) with square corners throughout,
    since it's a real top-level window now rather than a floating child.
    - Annotation-category arrow tile reuses the regular Arrow icon.
    - Text annotation icon is now a hollow black-outlined box with black
    text instead of a solid black box with white text.
    - Font combo boxes filter to scalable fonts only, avoiding DirectWrite
    console warnings from bitmap fonts like Fixedsys.
    - Font/font size/ta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
2026-09-04 Refine text and scale bar annotations, popup on-screen clamp
    Text annotations:
    - Customize popup for text hides every option that doesn't apply
    (description, unit/decimals, tag width, line/outline/fill, etc.) and
    relabels the Title field to "Text Contents".
    - The old "Text BG Transparency" control is gone; text now honors the
    shared Opacity control (invisible at 0, fully visible at 1), fading
    box and glyphs together.
    - Dragging a text object while its popup is open no longer snaps back on
    apply/cancel — the menu preserves the live tag offset (and other
    positional state) instead of its open-time snapshot.
    - No stray endpoint dot is drawn under a hovered/dragged text box.
    Scale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
2026-09-04 Union midpoint into line stroke, fix cap/midpoint zoom squish, popup styling
    - The line midpoint marker is now built as a filled band and unioned
    into the line's own outline/fill paths, so it reads as one continuous
    stroke instead of a separate marker laid on top.
    - Finalized polylines (and their caps and midpoint markers) are built
    and painted in device space with the pan/zoom transform reset, so the
    round/triangular cap shapes and midpoint ticks no longer squish into
    ellipses when the current zoom's x/y scale is non-uniform. Output is
    identical under uniform or no zoom.
    - Customize popup panel now uses the app's near-white sidebar-panel fill
    and group-box border so it reads a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
2026-09-04 Point marker styles, pyramid full-res export guard
    - Point measurements now support several marker styles (meta.point_style):
    dot (the original filled disc), circle (hollow ring), square, diamond,
    cross, x, and triangle — with a style picker in the customize popup.
    Every style stays undistorted under a non-uniform zoom the same way
    the dot always has (each vertex offset pre-divided by its own axis
    scale before the ambient paint transform corrects it back).
    - A pyramid-backed loaded image (LargeImageSource.is_pyramid) disables
    the full-resolution export kinds — reading one's full native region
    can mean decoding a multi-gigapixel image into memory — falling back
    to Previe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
2026-09-05 Fix initial tile selection, calibration resume, and scale bar control layout; count numbers show while placing
    - Selecting a category now selects its first tile the same way clicking
    a tile does (setChecked alone never fired the selection signal),
    which also fixes calibration not resuming a tile when none had been
    explicitly selected yet
    - Scale bar: decimals control restored (its own field next to Unit),
    Bar Margin moved below Bar Padding, and a dedicated Background Color
    picker added below Bar Color
    - Count tool now draws each point's number as it's placed, not only
    once finalized
    Claude-Session: https://claude.ai/code/se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
2026-09-05 Redesign count icon layout; capture calibration-resume tile at panel open
    - Count icon: numbers were still clipping/overlapping with the
    scattered-triangle point layout; switched to a vertical column of
    points with each label to its right, so nothing overlaps and no point
    sits near an edge
    - The tile to resume after calibration was only ever captured when
    manual line placement actually started, so closing the "Calibrate
    DPI" panel any other way (direct DPI entry, or toggling it shut
    without touching manual placement) never restored the prior
    selection; now captured once at the panel's own hidden-to-visible
    transition, covering every way it later closes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
2026-09-05 Restore triangle count icon with outward labels; clamp on-screen tags; earlier previews for 2-circle and 4pt perp
    - Count icon: back to a triangle of dots (not a column), with each
    number placed to the outward side of its own dot instead of all three
    crowding the triangle's middle
    - Every drawn measurement tag now nudges itself to stay fully inside
    the visible viewport, computed against the actual paint transform —
    fixes a shallow 4 Point Angle's tag landing off-screen, and covers
    any other kind whose label anchor lands near an edge
    - Radius 2 Circle: the dashed center-to-center connector now previews
    as soon as the second circle's center is placed (or being hovered),
    instead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
2026-09-05 Count icon numbers above dots; add manual/automatic choice to DPI calibration wizard
    - Count icon: numbers now sit directly above their own dot, matching
    how they actually render on the preview, instead of off to the side
    - DPI Calibration wizard: new "Choose Calibration Method" step after
    "Align the camera" — Automatic continues into the existing slide
    routine (tick detection, capture, mosaic QC, which still offers a
    manual fallback line if the measured DPI looks wrong); Manual instead
    jumps straight to its own step (place a reference line, enter its
    length, Finish), skipping the automatic routine entirely. Going back
    past "Choose" resets which path was taken.
    Co-Authored-B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
2026-09-06 Space out count icon points; de-orange automatic calibration; rework manual DPI step
    - Count icon: points 1 and 3 pushed further from point 2 so the
    triangle reads less cramped
    - "Automatic DPI Calibration" no longer uses the orange emphasis style
    shared with actual capture-running buttons
    - Manual DPI Calibration step: placement now arms itself (and disables
    click-to-move) as soon as the step appears, instead of requiring
    "Place Calibration Line" to be pressed first; "Apply" moved to its
    own line, renamed "Calculate DPI", next to the DPI field it fills in;
    step text now mentions the zoom tools and Ctrl+scroll for precise
    placement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
2026-09-06 DPI calibration wizard: back-to-selection button, fix clipped content, streamline manual step
    - Add "Back to Calibration Selection" button on the wizard's first step
    - Fix the "Choose Calibration Method" step's text getting vertically
    clipped, and the bottom of the manual step's content getting clipped
    on switching to it — both from a word-wrapped label/newly-shown
    controls not always repropagating a resize request up through the
    nested CollapsibleSection/QScrollArea chain
    - Manual DPI Calibration step: removed the now-pointless "Place
    Calibration Line" toggle (placement is armed by default); labeled the
    length field "Distance:" and the DPI field "DPI:"; disabled scroll-
    whee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
2026-09-06 Replace disabled first-step Previous with a Cancel Calibration button
    Both the Camera Space and DPI calibration wizards showed a permanently
    greyed-out Previous button on their first step, doing nothing. Replaced
    it there with a "Cancel Calibration" button (sharing the same nav row
    slot, toggled by visibility like Next/Finish already are) that bails
    out to the calibration selection list — the same action the DPI
    wizard's own "back to selection" already did, just now surfaced in
    Previous's old spot instead of a separate button/row.
    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
2026-09-06 Revert DPI and skip to manual step when automatic calibration fails or fails QA
    StitchAndMeasureRoutine writes settings.dpi as soon as it computes any
    number at all, trustworthy or not — so a failed run, or one that
    completed but didn't pass QA, could still leave a bogus DPI in place.
    Now restores whatever DPI was on record before the attempt and jumps
    straight to the manual step (skipping Quality Control, which would
    otherwise have nothing trustworthy to show) so the user can place a
    reference line themselves right away.
    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
2026-09-06 Defer jump to manual step until after the results dialog's event loop settles
    Arming calibration-line placement (and suppressing click-to-move)
    happened immediately after the QA-failure results dialog closed, which
    could still leave pending focus/activation events in the queue that
    landed afterward and clobbered it — the wizard would show the manual
    step but clicks still moved the stage instead of placing a point.
    Deferring the jump via QTimer.singleShot(0, ...) lets those settle
    first, so the arm sticks.
    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
2026-09-12 Base pyramid TIFF ETA on average rate instead of last step
    Extrapolating from a single step amplified normal per-step jitter by
    (100 - percent), swinging the estimate by hundreds of seconds on a real
    8GB run. The average rate since start damps that noise while still
    tracking drift in the overall rate over a long run.
    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
2026-09-23 Fixed Camera Calibration not working on high resolutions + tweaks to calibration
    [models.py]
2026-09-23 Add COM port selection to controller settings and remember last port
    The Controller settings group now has a COM port dropdown (Auto-detect or a
    specific port, with a Refresh button). Auto-detect probes the last successful
    port first and persists it after connecting, so startup skips probing
    unrelated ports.
    Claude-Session: https://claude.ai/code/session_016MwXsvkowxAnSFQ2WJFTkK
    [motion_config.py, motion_controller.py]
2026-09-23 Reconnect motion controller when the serial port or baud rate is saved
    Saving a new port or baud rate in the navigation settings now restarts the
    controller with the live settings instead of waiting for an app restart.
    Message listeners are kept on the manager so they survive the restart, and
    port probing stops early when the controller is shutting down.
    Ports are opened exclusively so Linux cannot silently share a tty between
    processes, open failures are logged (with a dialout hint for permission
    errors on Linux), and the port list includes /dev/serial/by-id links.
    Claude-Session: https://claude.ai/code/session_016MwXsvkowxAnSFQ2WJFT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
    [motion_controller.py, motion_controller_manager.py]
2026-09-23 Add Connect button for the serial port and toast on connection failure
    The Controller settings group has a Connect button that saves only the
    selected port and reconnects immediately. When the motion controller fails
    to connect, at startup or after a reconnect, an error toast explains why.
    The state poller now always reports the first state of a restarted
    controller so a repeated failure is not swallowed, and restarts are
    serialised so overlapping requests cannot race.
    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
    [motion_controller.py, motion_controller_manager.py]
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2026-09-23 Stitch tree cores as a post-processing step after focus stacking
    Port misc/image_stitching/stitchCli.py into TreeCoreStitchRoutine. The
    tree core routine queues one per slot once its frames are captured, and
    the routine waits on each of that slot's focus stacks before stitching,
    so it never starts on a partial set.
    Frame order, orientation (vertical core) and direction (reverse) come
    from the camera calibration and each frame's stage position, falling
    back to matching whole neighbouring frames when either is missing. The
    overlap is derived the same way unless set manually. The calibration
    slide is prepended when it was imaged; the composite is not cropped.
    The step between frames can now b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
    [motion_config.py]
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
